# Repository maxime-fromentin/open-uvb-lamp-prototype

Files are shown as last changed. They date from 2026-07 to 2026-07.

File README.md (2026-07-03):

# Open UVB Lamp Prototype

Prototype narrowband UVB lamp using a Philips PL-S 9W/01/2P lamp, a G23 electromagnetic ballast, a FreeCAD-designed enclosure, and a mechanical relay controlled by a Seeed XIAO RP2040.

The project is documented in the context of localized narrowband UVB exposure research for psoriasis-related prototyping. It is not medical advice and does not claim to treat, cure, or diagnose psoriasis.

The photos and videos in this README are presentation assets for the physical prototype and its assembly. They are included for documentation and inspection only.

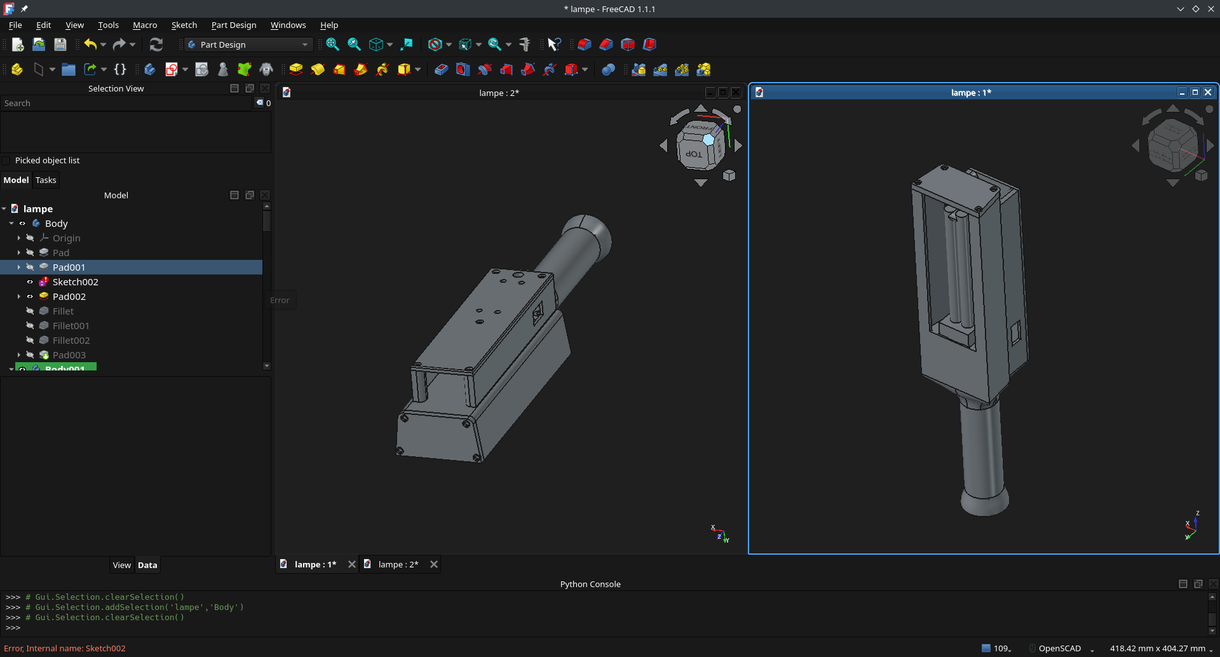
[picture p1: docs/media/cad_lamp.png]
CAD model


| Prototype handling | Visible lamp test |
| --- | --- |
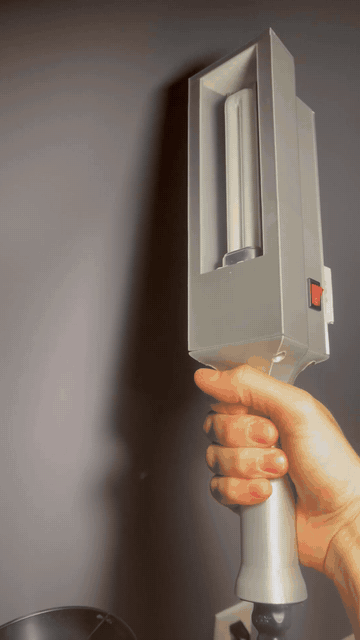
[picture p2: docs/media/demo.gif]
Prototype handling demo
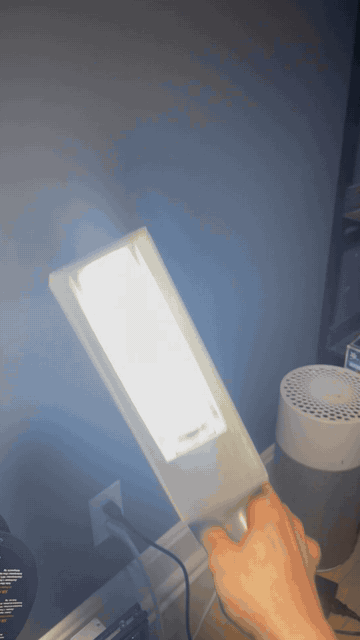
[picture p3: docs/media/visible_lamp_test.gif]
Visible non-UV lamp test
|  |  |

The illuminated lamp shown above is a visible, non-UV G23 test lamp used to verify fit, wiring behavior, and demonstration footage without UV exposure.

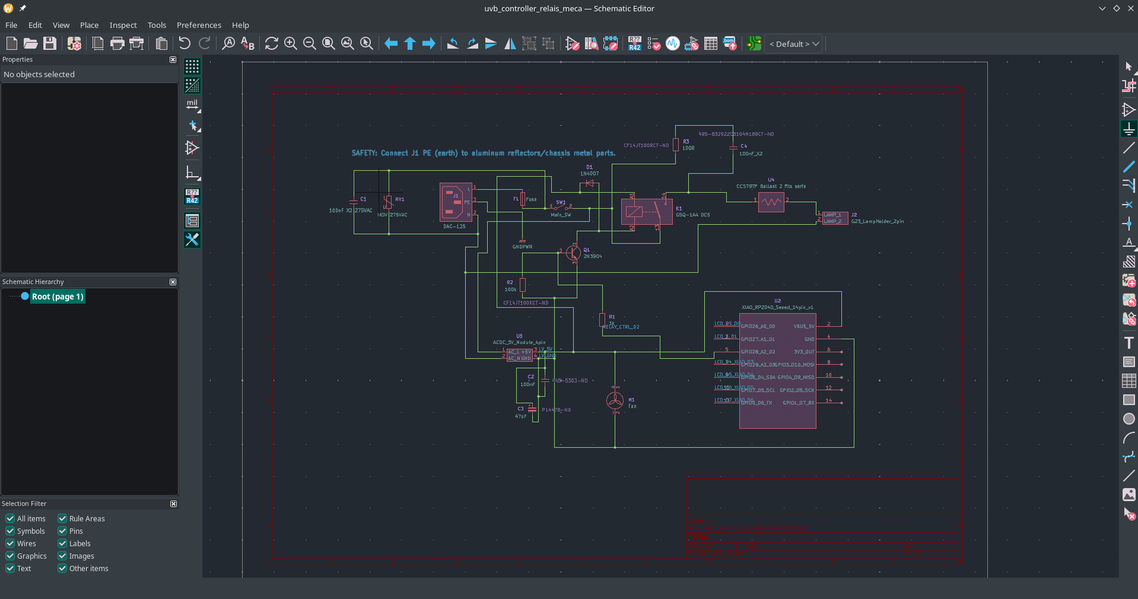
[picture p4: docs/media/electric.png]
Electrical schematic overview


Electrical schematic overview in KiCad. The schematic is provided as a wiring and soldering reference, not as a certified electrical validation.

> Project status: documented prototype. This repository is not a safety certification, a validated medical device, or a build guide for unqualified users.

## Critical Warning

This project combines 120 VAC mains voltage with a UVB source. UVB exposure can cause skin burns, eye injury, and long-term tissue damage. Mains voltage can kill.

The KiCad schematic is mainly a wiring and soldering aid for understanding the prototype. It is not a complete electrical simulation, a regulatory validation, a medical validation, or proof that the device is safe.

KiCad ERC/DRC checks can catch some connection errors, but they do not validate safety with mains voltage, ballasts, UVB lamps, or therapeutic use.

This repository is intended for documentation and private technical reference. It is not a certification file, a warranty of safety, or a substitute for qualified electrical, mechanical, or medical review.

## Burn-Risk Control Features

The prototype is designed around the idea that UVB exposure must be time-limited, distance-aware, and measured. These controls are intended to reduce burn risk, but they do not make the device medically safe by themselves:

- **Relay-controlled shutoff:** the lamp power path is switched by a mechanical relay so the controller can interrupt exposure.
- **Default-off firmware behavior:** the test firmware drives the relay OFF at boot and only turns it ON after an explicit command.
- **Short timed pulse during tests:** the current relay test firmware limits `on` and `pulse` commands to 5 seconds.
- **Physical shielding:** the enclosure concept is intended to block stray UV and expose only the target area.
- **Distance control concept:** a fixed distance guide or visual distance reference should be used because UV dose changes strongly with distance.
- **Cooling and thermal checks:** ventilation and temperature checks are part of the prototype notes because lamp temperature can affect output and enclosure safety.
- **Required UV measurement:** actual UVB irradiance must be measured with a suitable meter before any exposure assumptions are made.

These features are engineering risk controls, not a treatment protocol. Dose limits, exposure schedules, and suitability for psoriasis phototherapy require qualified medical guidance.

The media in this README show the prototype as built, including the FreeCAD enclosure, the visible non-UV test lamp, and the electrical layout. They are not proof of safety or clinical suitability.

## Retained Design

The retained design is the mechanical-relay schematic:

- KiCad source: `kicad_uvb_project/uvb_controller/uvb_controller_mechanical_relay.kicad_sch`
- KiCad project: `kicad_uvb_project/uvb_controller/uvb_controller.kicad_pro`
- Local symbol library: `kicad_uvb_project/uvb_controller/uvb_custom.kicad_sym`
- Schematic PDF: `output/pdf/uvb_controller_mechanical_relay.pdf`

Older schematic variants are kept in `kicad_uvb_project/uvb_controller/archive/` for historical reference only.

## Repository Contents

- `CAD/`: FreeCAD source files, STEP model, and mechanical reference images.
- `kicad_uvb_project/`: KiCad schematic, relay BOM, placement notes, and connection maps.
- `sketch_relay_test/`: XIAO RP2040 relay test firmware.
- `XIAO_RELAY_TEST_SOFTWARE.md`: compile, flash, and serial test notes.
- `SAFETY.md`: essential safety notes.
- `digikey_bom_clean.csv`: public supplier-oriented BOM with personal sourcing links removed.
- `docs/media/`: README media assets, including the demo GIF.

## Reproducing the Prototype

The repository includes the core files needed to inspect and reproduce the documented prototype:

- Mechanical design in FreeCAD: `CAD/lampe.FCStd`, `CAD/CadLampe.FCStd`, `CAD/Fan_80x80x38_equivalent.step`, and `CAD/G23_lamp_dimensions.md`.
- Electrical wiring reference: `kicad_uvb_project/uvb_controller/uvb_controller_mechanical_relay.kicad_sch` and `output/pdf/uvb_controller_mechanical_relay.pdf`.
- KiCad custom symbols: `kicad_uvb_project/uvb_controller/uvb_custom.kicad_sym`.
- Parts list: `digikey_bom_clean.csv` and `kicad_uvb_project/BOM_mechanical_relay.csv`.
- Firmware: `sketch_relay_test/sketch_relay_test.ino`.
- Firmware test notes: `XIAO_RELAY_TEST_SOFTWARE.md`.
- Safety notes: `SAFETY.md`.

Vendor datasheets are referenced by URL in the BOM rather than copied into the repository.

## Firmware Test

The test firmware forces the relay OFF at boot and waits for a serial command:

- `on`: turns the relay on for 5 seconds.
- `pulse`: same as `on`.
- `off`: immediately turns the relay off.
- `status`: prints the current state.

Keep mains voltage disconnected during USB and firmware tests.

## Minimum Validation Before Use

Before any mains or UVB test, document at least:

- protective earth continuity to accessible metal parts;
- no continuity between mains `L/N` and logic `5V/GND`;
- fuse on the live conductor;
- UV-opaque enclosure and ventilation;
- thermal measurement;
- UVB irradiance measurement with a suitable meter;
- ideally, a 250-400 nm spectral measurement.

## License

See `LICENSE.md`.

Proposed license split:

- Hardware, CAD, KiCad files, BOMs: CERN-OHL-P-2.0.
- Firmware: MIT.
- Documentation, photos, and videos: CC-BY-4.0.

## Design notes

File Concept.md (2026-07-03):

# Project Concept

The goal is to document a DIY narrowband UVB lamp prototype based on a Philips PL-S 9W/01/2P lamp. The design aims to capture practical FreeCAD files, wiring, BOM, safety, and test notes so that another technically competent person can understand the build.

This is not a finished medical device. The main value of the repository is transparency: mechanical files, wiring intent, BOM choices, test firmware, and safety assumptions are kept together.

The project is documented in a psoriasis-related prototyping context because narrowband UVB is commonly associated with clinical phototherapy. This repository does not provide a treatment protocol and does not claim medical efficacy.

## Target Lamp

- Philips UV-B Narrowband PL-S 9W/01/2P.
- G23 two-pin base.
- The lamp emits around 360 degrees, so a reflector is needed to avoid wasting much of the output.
- Internal wiring should use appropriately rated wire, such as AWG 18 or equivalent where suitable.

## Mechanical Ideas

- UV-opaque enclosure.
- Polished aluminum reflector.
- Light-trap ventilation path to block direct UV leakage while allowing airflow.
- Heat-resistant mounting near the lamp holder; PLA may soften near warm components.
- Metal or wood isolation plate around the lamp socket if needed.

## Controls and Safety Features

Potential features to document or add:

- redundant timer;
- visual distance guide, such as two angled lasers or a removable distance gauge;
- active cooling;
- red LCD display for readability through amber protective goggles;
- calibration or validation using a UVB meter;
- protective eyewear certified for UV exposure;
- skin shielding for areas that should not be exposed.

## Power and Ballast

The retained design uses a mechanical relay and an electromagnetic ballast approach. A conventional ferromagnetic ballast can be more tolerant in this kind of prototype than some compact electronic switching approaches, but every selected part still needs independent review.

Add a fuse holder on the live input conductor. A GFCI-protected outlet or power strip is strongly recommended for bench testing.

## Validation Ideas

- Use a spectroradiometer capable of measuring roughly 250-400 nm to verify the spectral output.
- Use a UVB radiometer, such as a Solarmeter-style meter, to measure irradiance in mW/cm2 at the actual working distance.
- Compare measurements against a known commercial phototherapy device only if the same measurement setup and distance are used.
- Use a thermal camera or contact temperature measurements to verify cooling.

## Risk Example

If the expected output is 3 mW/cm2 but the real build produces 6 mW/cm2 at the same distance, a two-minute exposure gives twice the intended dose. This is why measured output matters more than design assumptions.

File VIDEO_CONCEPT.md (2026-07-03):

# Video Concept

Goal: short demonstration video for the repository README and project page.

Suggested content:

- show the assembled prototype;
- show the mechanical layout and lamp holder;
- show the relay test behavior with mains disconnected where appropriate;
- include thermal and UV measurement footage when available;
- explain the limitations of the prototype without making medical claims.

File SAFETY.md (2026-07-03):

# Safety Notes

## Your Responsibilities

- **Competence:** do not reproduce or modify this build unless you have real electrical and mechanical competence for mains-powered UV equipment.
- **Shielding:** the enclosure must be fully opaque to UV radiation.
- **Eye protection:** use certified UV protective eyewear, for example EN 170 goggles marked `2C-1.2` or equivalent. Never look at the bare lamp, even briefly.
- **Ventilation:** UV lamps heat up, and their output spectrum can vary with temperature. Provide airflow if the lamp is enclosed.
- **Mains safety:** protect the live conductor with a fuse, bond accessible metal parts to protective earth, and keep mains wiring physically separated from low-voltage electronics.
- **Measurement:** do not rely on assumed dose. Measure UVB irradiance and, ideally, the emitted spectrum before any exposure.

This repository documents a prototype. It does not make the device medically or electrically safe by itself, and it does not replace professional review or local compliance obligations.

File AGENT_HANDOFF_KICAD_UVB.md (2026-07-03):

# Project Notes: UVB Prototype

This file is kept as a short public handoff note. It intentionally contains no personal paths, names, locations, credentials or private configuration.

## Current retained design

- Active electrical schematic: `kicad_uvb_project/uvb_controller/uvb_controller_mechanical_relay.kicad_sch`
- KiCad project: `kicad_uvb_project/uvb_controller/uvb_controller.kicad_pro`
- Local symbol library: `kicad_uvb_project/uvb_controller/uvb_custom.kicad_sym`
- Public schematic PDF: `output/pdf/uvb_controller_mechanical_relay.pdf`

## Design intent

The retained variant uses a mechanical relay controlled by a Seeed XIAO RP2040 relay driver circuit. The schematic is intended as a wiring and soldering aid for the prototype, not as a certified electrical design or complete simulation.

## Publication notes

- Do not publish API credentials, private supplier quotes, local filesystem paths or personal marketplace links.
- Keep obsolete schematic variants in `kicad_uvb_project/uvb_controller/archive/` only as historical references.
- Review the safety warning in `README.md` before publishing.

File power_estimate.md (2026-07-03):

# Power and Current Estimate

## Estimated Power

- Lamp + ballast: roughly 12 to 18 W, including ballast losses.
- Fan: roughly 1 to 15 W depending on the selected fan type.
- Control electronics: roughly 1 to 4 W.
- Typical total: roughly 14 to 37 W.

## Mains Current at 120 VAC

Using `I = P / V`:

- Low estimate: `14 W / 120 V = 0.117 A`
- High estimate: `37 W / 120 V = 0.308 A`

Use these values only as first-order sizing estimates. Actual current, inrush, ballast behavior, and thermal behavior must be measured on the assembled prototype.

## Relay and Control Note

The low-voltage XIAO output only controls the relay driver transistor. It does not power the AC load directly.

The relay contact, wiring, fuse, switch, inlet, ballast, and all mains clearances must be selected and reviewed for the real AC load, including inrush current.

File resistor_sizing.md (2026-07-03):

# SSR Input Resistor Sizing

Date: 2026-05-07

This note is retained for the earlier SSR variant. The retained public schematic now uses the mechanical relay design, but the calculation remains useful historical context.

## Context

- Microcontroller: ESP32-WROOM, 3.3 V GPIO.
- SSR candidate: Panasonic AQH3213.
- Datasheet assumptions:
  - input LED forward voltage: approximately `Vf = 1.2 to 1.3 V`;
  - maximum trigger LED current: `Ift_max = 10 mA`.

Goal: choose a series resistor that can trigger the SSR from a 3.3 V GPIO.

## Formula

SSR LED current:

`I = (Vgpio - Vf) / R`

with `Vgpio = 3.3 V`.

## Candidate Values

### R = 220 ohms

- With `Vf = 1.2 V`: `I = (3.3 - 1.2) / 220 = 9.55 mA`
- With `Vf = 1.3 V`: `I = (3.3 - 1.3) / 220 = 9.09 mA`

Conclusion: borderline against `Ift_max = 10 mA`.

### R = 180 ohms

- With `Vf = 1.2 V`: `I = 11.67 mA`
- With `Vf = 1.3 V`: `I = 11.11 mA`

Conclusion: better trigger margin while still keeping GPIO current reasonable.

### R = 150 ohms

- With `Vf = 1.2 V`: `I = 14.00 mA`
- With `Vf = 1.3 V`: `I = 13.33 mA`

Conclusion: more margin, but higher GPIO load.

## Resistor Dissipation

`P = I^2 * R`

For `R = 180 ohms`, at roughly 11.1 to 11.7 mA:

- `P_min ~ 0.022 W`
- `P_max ~ 0.025 W`

A 1/4 W resistor is sufficient.

## Historical Recommendation

- Recommended SSR input resistor: **180 ohms**.
- Use one series resistor per SSR input.
- Keep firmware logic explicit, with the output OFF at boot.
- A transistor or MOSFET driver can be added later for stronger logic isolation and drive margin.

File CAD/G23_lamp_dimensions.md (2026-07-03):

# G23 Lamp Dimensions

This note collects approximate dimensions used to model the 9 W G23 lamp for the project.

## Known or Standard Reference Values

- Maximum overall length: about 6.5 in = 165.1 mm, often rounded to 165-167 mm.
- Power: 9 W.
- Base: G23, 2 pins.

## Approximate Values to Validate

- Tube diameter: about 11 to 12 mm, T4-style tube.
- Pin spacing: about 7.8 mm, G23 standard.
- Pin diameter: about 0.9 to 1.0 mm.
- Visible pin length: about 6 to 8 mm.
- Maximum width, tube outside to tube outside: about 28 to 32 mm.
- Plastic base: about 31 x 15.5 x 16 mm.
- Base shoulder or neck: about 27 x 13 x 6 mm.

## Measurements Needed for Final CAD

1. Exact overall length from pin tip to top of U-bend.
2. Exact maximum width from outside tube to outside tube.
3. Exact tube diameter.
4. Exact pin spacing and pin diameter.
5. Exact depth and height of the G23 base block.
6. U-bend height and radius.

## Note

The approximate values above are suitable for a first 3D mockup, but final geometry should be validated against the real lamp or an exact manufacturer datasheet.

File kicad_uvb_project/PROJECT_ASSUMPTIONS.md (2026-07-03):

# UVB Controller - Default Assumptions

- Input mains: `120 VAC / 60 Hz`
- AC wiring and low-voltage control wiring must be physically separated.
- Controller: `Seeed XIAO RP2040`.
- AC-DC supply: isolated AC-to-5V module or enclosed supply suitable for the enclosure.
- AC switching: mechanical relay on Live (L), driven through a transistor stage.
- External power connector:
- Cable: `NEMA 5-15P to IEC C13`.
- Appliance inlet or panel connector: `IEC C14` or equivalent rated inlet.
- UV lamp path:
- electromagnetic ballast;
- G23 socket;
- Philips PL-S 9W/01/2P lamp.

## Safety Notes

- Keep AC and low-voltage wiring separated.
- Add a fuse on AC Live before the downstream switch/load path.
- Bond accessible metal parts to protective earth where applicable.
- Place AC wiring away from MCU headers and USB access.
- Final validation should include creepage, clearance, strain relief, enclosure, grounding, thermal, and local-code review.

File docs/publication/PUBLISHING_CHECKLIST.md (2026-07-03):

# Publishing Checklist

Use this before making the GitHub repository public.

## Must do

- Rotate any Digi-Key/API credentials that were ever stored in local notes.
- Confirm `Bom.md` contains no API credentials.
- Confirm no personal paths remain, for example `/home/<name>`, `/run/media/<name>` or local mount paths.
- Confirm no personal marketplace links, private quote PDFs, addresses, phone numbers or emails are included.
- Confirm `datasheet/Quote_*.pdf` is not published unless manually reviewed.
- Publish only the retained schematic PDF: `output/pdf/uvb_controller_mechanical_relay.pdf`.
- Keep `uvb_controller_mechanical_relay.kicad_sch` as the active schematic.
- Keep archived schematics clearly marked as historical if they are published.

## Recommended repository files

- `README.md`
- `LICENSE.md`
- `.gitignore`
- `SAFETY.md`
- `Concept.md`
- `Bom.md`
- `digikey_bom_clean.csv`
- `kicad_uvb_project/BOM_mechanical_relay.csv`
- `kicad_uvb_project/PLACEMENT_GUIDE.md`
- `kicad_uvb_project/PROJECT_ASSUMPTIONS.md`
- `kicad_uvb_project/uvb_controller/uvb_controller.kicad_pro`
- `kicad_uvb_project/uvb_controller/uvb_controller_mechanical_relay.kicad_sch`
- `kicad_uvb_project/uvb_controller/uvb_custom.kicad_sym`
- `output/pdf/uvb_controller_mechanical_relay.pdf`
- `CAD/`
- `sketch_relay_test/sketch_relay_test.ino`
- `XIAO_RELAY_TEST_SOFTWARE.md`
- `docs/media/demo.gif` once available

## Do not publish by default

- `.tools/`
- `.arduino15/`
- `.code/`, `.agents/`, `.codex/`
- `build_relay_test/`
- `kicad_uvb_project/uvb_controller/fp-info-cache`
- `kicad_uvb_project/uvb_controller/uvb_controller-backups/`
- `datasheet/Quote_*.pdf`
- downloaded vendor datasheets unless their redistribution terms are clear

## Final safety wording

Make sure the README clearly states that the KiCad schematic is a wiring and soldering aid, not a certified electrical design, medical device validation, or complete numerical simulation.

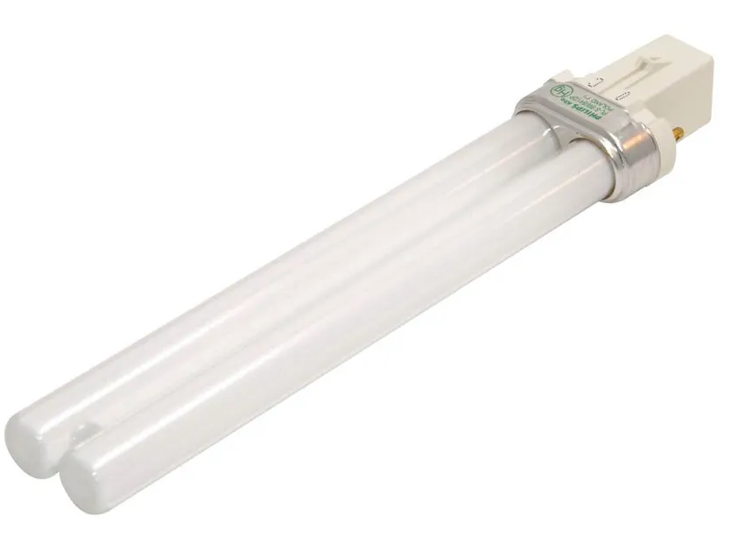
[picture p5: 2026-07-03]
CAD/Ampoule2.png

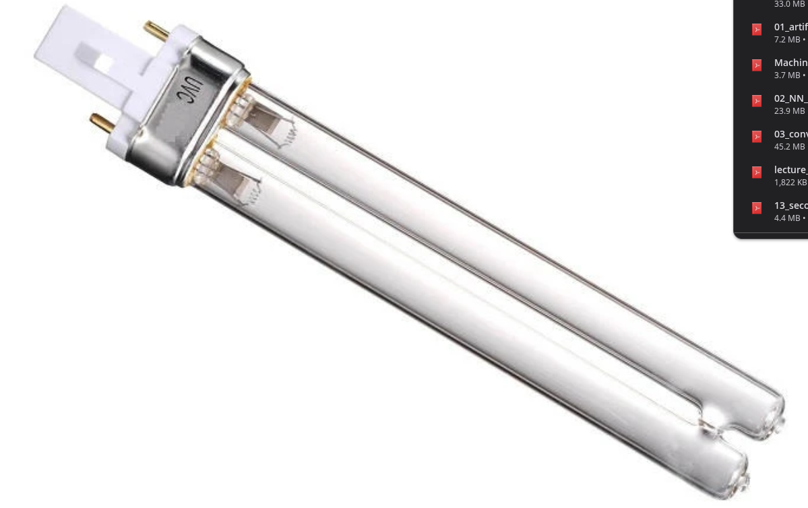
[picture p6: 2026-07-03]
CAD/Ampoule.png

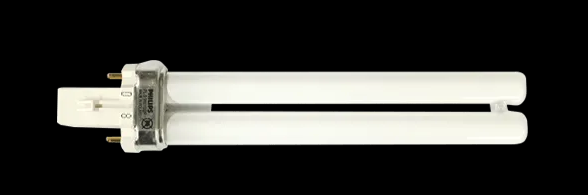
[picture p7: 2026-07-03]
CAD/Ampoule_cote.png

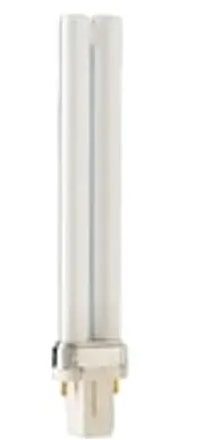
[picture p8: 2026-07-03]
CAD/Ampoule3.png

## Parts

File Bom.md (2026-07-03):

# BOM Notes

This file is an informal sourcing note. The structured public BOM is `digikey_bom_clean.csv`, and the KiCad-oriented relay BOM is `kicad_uvb_project/BOM_mechanical_relay.csv`.

## Main Items

- G23 lamp holder.
- Philips PL-S 9W/01/2P narrowband UVB lamp.
- Electromagnetic ballast compatible with the selected lamp.
- EN 170 or equivalent UV protective goggles.
- UV protective sleeve or shielding for non-target skin.
- AC fan or DC fan, depending on final enclosure design.
- AC-to-5V power module for the low-voltage control electronics.
- Seeed XIAO RP2040 relay controller.
- External mains cord and appliance inlet.
- Main AC switch.
- Fuse holder and fuse on live conductor.
- Polished aluminum reflector.
- Perfboard or prototyping board for the control circuit.
- Headers or sockets for removable controller mounting.

## Publication Note

Do not store API credentials, private supplier quotes, personal addresses, private marketplace links, or local filesystem paths in this repository. Use local environment variables for supplier API integrations.

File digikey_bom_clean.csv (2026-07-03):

item | number | manufacturer | mpn | unit_price_cad | quantity_available | airflow_cfm | product_description | detailed_description | product_url | datasheet_url | status
Appliance inlet IEC C14 panel mount | 1 | DIT | DAC-12S | 0.97 | 161 |  | IEC 60320 C14 appliance inlet panel mount | Input connector for external C13 power cord | https://www.digikey.com/en/products/detail/dit/DAC-12S/18681274 | //mm.digikey.com/Volume0/opasdata/d220001/medias/docus/5561/DAC%20Series.pdf | ready
Main AC rocker switch | 1 | ZF Electronics | SRB22A2FBRNN | 2.38 | 3201 |  | Rocker switch SPST 10A 125V | Main 120 VAC switch with current margin | https://www.digikey.com/en/products/detail/zf-electronics/SRB22A2FBRNN/446027 | https://switches-sensors.zf.com/wp-content/uploads/2024/08/Rocker_SRB_Datasheet_2024-08-02.pdf | ready
Panel fuse holder 5x20mm | 1 | Littelfuse Inc. | 82000000005 | 5.02 | 5163 |  | Fuse holder panel mount 5x20mm | Accessible enclosure fuse holder in series with Live | https://www.digikey.com/en/products/detail/littelfuse-inc/82000000005/653481 | https://www.littelfuse.com/assetdocs/820-821-823-824-series-datasheet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 | ready
Slow-blow fuse 5x20mm 250V | 2 | Bel Fuse Inc. | 5HT 1-R | 0.74 | 5193 |  | Fuse cartridge 5x20mm slow-blow 1A 250V | Main fuse plus one spare | https://www.digikey.com/en/products/detail/bel-fuse-inc/5HT-1-R/1008979 |  | ready
Slow-blow fuse 5x20mm 250V alternative | 2 | Bel Fuse Inc. | 5HT 1.6-R | 0.74 | 2573 |  | Fuse cartridge 5x20mm slow-blow 1.6A 250V | Alternative if startup inrush trips the 1A fuse | https://www.digikey.com/en/products/detail/bel-fuse-inc/5HT-1-6-R/1008981 |  | optional
AC SSR alternative | 0 | Panasonic Industry | AQH3213 | 2.69 | 2256 |  | SSR SPST-NO 1.2A 0-600V PhotoMOS | Historical alternative only; less robust for inductive ballast loads than mechanical relay | https://www.digikey.com/en/products/detail/panasonic-industry/AQH3213/2125782 | //mm.digikey.com/Volume0/opasdata/d220001/medias/docus/8457/AQ-H%20RELAYS.pdf | optional
Main AC mechanical relay | 2 | Omron Electronics Inc-EMC Div | G5Q-1A4 DC5 | 1.77 | 4715 |  | Relay SPST-NO 5V coil 10A 277VAC through-hole | Primary ballast/lamp switching relay; one installed plus one spare | https://www.digikey.com/en/products/detail/omron-electronics-inc-emc-div/G5Q-1A4-DC5/1815721 | https://components.omron.com/sites/default/files/datasheet_pdf/J155-E1.pdf | ready
NPN relay driver transistor | 4 | Diotec Semiconductor | 2N3904 | 0.14 | 75720 |  | NPN transistor through-hole TO-92 | Relay coil driver from XIAO GPIO | https://www.digikey.com/en/products/detail/diotec-semiconductor/2N3904/13164701 | https://diotec.com/request/datasheet/2n3904.pdf | ready
Relay flyback diode | 4 | Diotec Semiconductor | 1N4007 | 0.14 | 334537 |  | Rectifier diode 1kV 1A through-hole | Flyback protection across relay coil | https://www.digikey.com/en/products/detail/diotec-semiconductor/1N4007/18833652 | https://diotec.com/request/datasheet/1n4001.pdf | ready
Relay driver base resistor | 4 | Stackpole Electronics Inc | RNMF14FTC1K00 | 0.14 | 4024 |  | Through-hole resistor 1k ohm 1/4W 1% | Limits transistor base current | https://www.digikey.com/en/products/detail/stackpole-electronics-inc/RNMF14FTC1K00/2617329 | https://www.seielect.com/catalog/SEI-RNF_RNMF.pdf | ready
Electromagnetic ballast 120VAC 1x9W G23 | 1 | Candela Corporation | CC579TP | 18.28 | 54 |  | Magnetic ballast candidate for Philips PL-S 9W/01/2P | G23 2-pin 7W/9W compatible; supplier listing price converted from USD at 1.4 | https://www.candelacorp.com/product/CC579TP |  | ready
G23 2-pin lamp holder | 2 | Candela Corporation | 1185-9-2H | 2.52 | 37 |  | Lampholder/socket for PL-S 9W/01/2P | Selected option for chassis mounting; supplier listing price converted from USD at 1.4 |  | https://www.candelacorp.com/spec/?prod_num=1185-9-2H | ready
G23 2-pin lamp holder alternative | 0 | Candela Corporation | 1185-9-VS1 | 2.52 | 25 |  | Vertical snap-in G23 socket | Alternative only | https://www.candelacorp.com/spec/?prod_num=1185-9-VS1 |  | optional
UVB lamp PL-S 9W/01/2P | 1 | Philips | PL-S 9W/01/2P | 75.00 | available |  | Narrowband UVB lamp | Target compatibility lamp; verify availability before ordering | https://solarcsystems.ca/product/philips-pl-s9w01-bulb/ |  | not_selected
XIAO RP2040 controller | 2 | Seeed Technology Co. Ltd | 102010428 | 7.05 | 4275 |  | Seeed XIAO RP2040 | Low-voltage relay controller board | https://www.digikey.com/en/products/detail/seeed-technology-co-ltd/102010428/14672129 | https://files.seeedstudio.com/wiki/XIAO-RP2040/res/rp2040_datasheet.pdf | ready
External wall-to-device power cord | 1 | Same Sky | AC-C13-NA | 6.7 | 21787 |  | NEMA 5-15P to IEC 60320 C13 power cord | 18 AWG 3-conductor 6 ft cord | https://www.digikey.com/en/products/detail/same-sky-formerly-cui-devices/AC-C13-NA/3479176 | https://www.sameskydevices.com/product/resource/digikeypdf/ac-c13-na.pdf | ready
USB-A to USB-C programming cable | 1 | GlobTek Inc. | USBA2C1MOUSBC(R) | 2.71 | 5334 |  | USB 2.0 cable Type-A male to Type-C male | Programming and test cable for XIAO RP2040 | https://www.digikey.com/en/products/detail/globtek-inc/USBA2C1MOUSBC-R/12546298 |  | ready
Internal AWG18 wire | 1 | Generic | 18 AWG stranded hookup wire | 19.95 | available |  | Hook-up wire for internal wiring | Use wire with appropriate voltage and temperature rating |  |  | ready
5V DC fan | 1 | Qualtek | FAD1-04010BBLW11 | 8.88 | 1668 | 4.2 | Fan axial 40x40x10mm ball 5VDC | Low-voltage cooling fan candidate | https://www.digikey.com/en/products/detail/qualtek/FAD1-04010BBLW11/2600052 |  | ready
Male 2.54mm headers for XIAO | 2 | Same Sky | SSK01-MPH-254-A7 | 0.23 | 4988 |  | Header strip 1x7 2.54mm through-hole | Allows XIAO pins to plug into socket headers | https://www.digikey.com/en/products/detail/same-sky-formerly-cui-devices/SSK01-MPH-254-A7/28772111 | https://www.sameskydevices.com/product/resource/digikeypdf/ssk01-mph-254.pdf | ready
Female 2.54mm socket headers for XIAO | 2 | Adam Tech | RS1-07-G | 0.62 | 2772 |  | Socket header 1x7 2.54mm through-hole | Removable XIAO mounting on protoboard | https://www.digikey.com/en/products/detail/adam-tech/RS1-07-G/9832045 | https://app.adam-tech.com/products/download/data_sheet/203013/rs1-xx-g-data-sheet.pdf | ready
UV protective arm sleeve | 1 | Generic | UV protective arm sleeve | 5.00 | available |  | UV protective sleeve for non-target skin | Verify UV rating before use |  |  | ready
UV protective goggles EN 170 | 1 | Solarc Systems / SolRx | UV Protective Patient Goggle - Amber Tint | 24.84 | available |  | Patient UV protective goggles | Supplier listing states UV and blue-light blocking | https://solarcsystems.com/product/uv-protective-patient-goggles-amber-tint/ |  | ready
Polished aluminum reflector sheet | 1 | Generic | Polished aluminum sheet | 2.00 | available |  | Polished or polishable aluminum reflector material | Avoid publishing personal marketplace links |  |  | ready
Compact protoboard 80x50mm | 2 | BusBoard Prototype Systems | PAD1 | 6.00 | 184 |  | FR4 perfboard 80mm x 50mm 2.54mm | Compact prototyping board for relay and control wiring | https://www.digikey.com/en/products/detail/busboard-prototype-systems/PAD1/19200381 | http://www.busboard.com/documents/datasheets/BPS-DAT-(PAD1)-Datasheet.pdf | ready
Visible G23 9W test lamp | 1 | Candela Corporation | PL-S9W/41 | 10.63 | 38 |  | 9W 4100K G23 visible lamp | Visible-light test lamp option | https://www.candelacorp.com/product/PL-S9W/41 |  | ready
Visible G23 9W test lamp alternative | 0 | Candela Corporation | F9TT/27K | 10.63 | 31 |  | 9W 2700K G23 visible lamp | Visible-light test lamp alternative | https://www.candelacorp.com/product/F9TT/27K |  | optional
Supplier shipping estimate | 1 | Candela/UPS | SHIPPING_Candela_UPS | 35.00 |  |  |  | Verify shipping at checkout |  |  | ready
Enclosed AC/DC 5V 15W module | 2 | MEAN WELL USA Inc. | RS-15-5 | 8.60 | 617 |  | Enclosed AC/DC converter 85-264VAC to 5VDC 15W | Chassis-mounted enclosed power supply option | https://www.digikey.com/en/products/detail/mean-well-usa-inc/RS-15-5/7706168 | https://www.meanwell.com/Upload/PDF/RS-15/RS-15-SPEC.PDF | ready
MOV 275VAC across L-N | 2 | TDK Electronics | B72214S0271K101 | 0.25 | 17844 |  | Varistor MOV 275VAC radial | Mains transient suppression across Live-Neutral after fuse | https://www.digikey.com/en/products/detail/tdk/B72214S0271K101/593838 |  | ready
MOV 275VAC robust alternative | 0 | TDK Electronics | B72214S2271K151 | 0.37 | 12881 |  | Varistor MOV 275VAC radial 6kA | Higher surge-energy alternative | https://www.digikey.com/en/products/detail/tdk/B72214S2271K151/6159482 |  | optional
X2 safety capacitor 0.1uF 305VAC | 2 | TDK Electronics | B32922C3104M189 | 0.47 | 78499 |  | Film capacitor safety class X2 through-hole | EMI/RFI filtering across Live-Neutral after fuse | https://www.digikey.com/en/products/detail/tdk/B32922C3104M189/2269407 |  | ready

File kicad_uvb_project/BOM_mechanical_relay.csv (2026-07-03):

reference | category | value | notes
C1 | Capacitor | 100nF X2 275VAC | Mains safety capacitor across L-N after F1
D1 | Diode | 1N4007 | Flyback diode across relay coil
F1 | Fuse | Fuse | Mains input fuse on live
J1 | Connector | DAC-12S | IEC C14 AC input
J2 | Connector | G23_LampHolder_2pin | G23 lamp holder / socket
K1 | Relay | G5Q-1A4 DC5 | Mechanical relay coil 5VDC SPST-NO
M1 | Fan | Fan | 5V fan on low-voltage rail
Q1 | Transistor | 2N3904 | NPN relay driver transistor
R1 | Resistor | 1k | Base resistor for Q1 from XIAO GPIO28_A2_D2
RV1 | Varistor | MOV 275VAC | Mains surge suppressor across L-N after F1
SW1 | Switch | Main_SW | Main AC switch
U2 | MCU | XIAO_RP2040_Seeed_14pin_v1 | Main controller board/header
U4 | Ballast | Ballast_1xLamp_4pin | Ballast interface / terminal abstraction
U5 | ACDC | ACDC_5V_Module_4pin | AC-DC 5V module

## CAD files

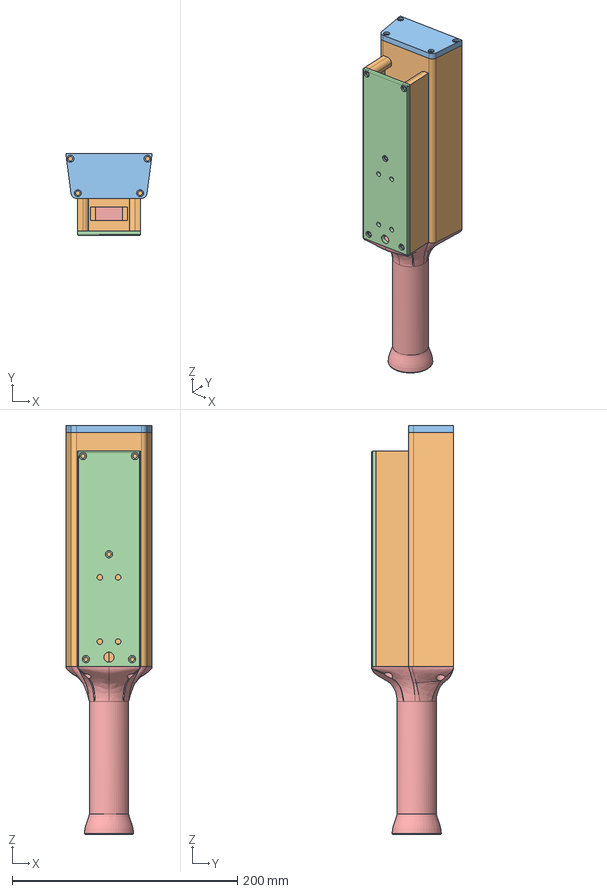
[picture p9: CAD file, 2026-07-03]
CAD/lampe.FCStd
76.7 x 73.0 x 363.0 mm

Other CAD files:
CAD/CadLampe.FCStd
CAD/Fan_80x80x38_equivalent.step

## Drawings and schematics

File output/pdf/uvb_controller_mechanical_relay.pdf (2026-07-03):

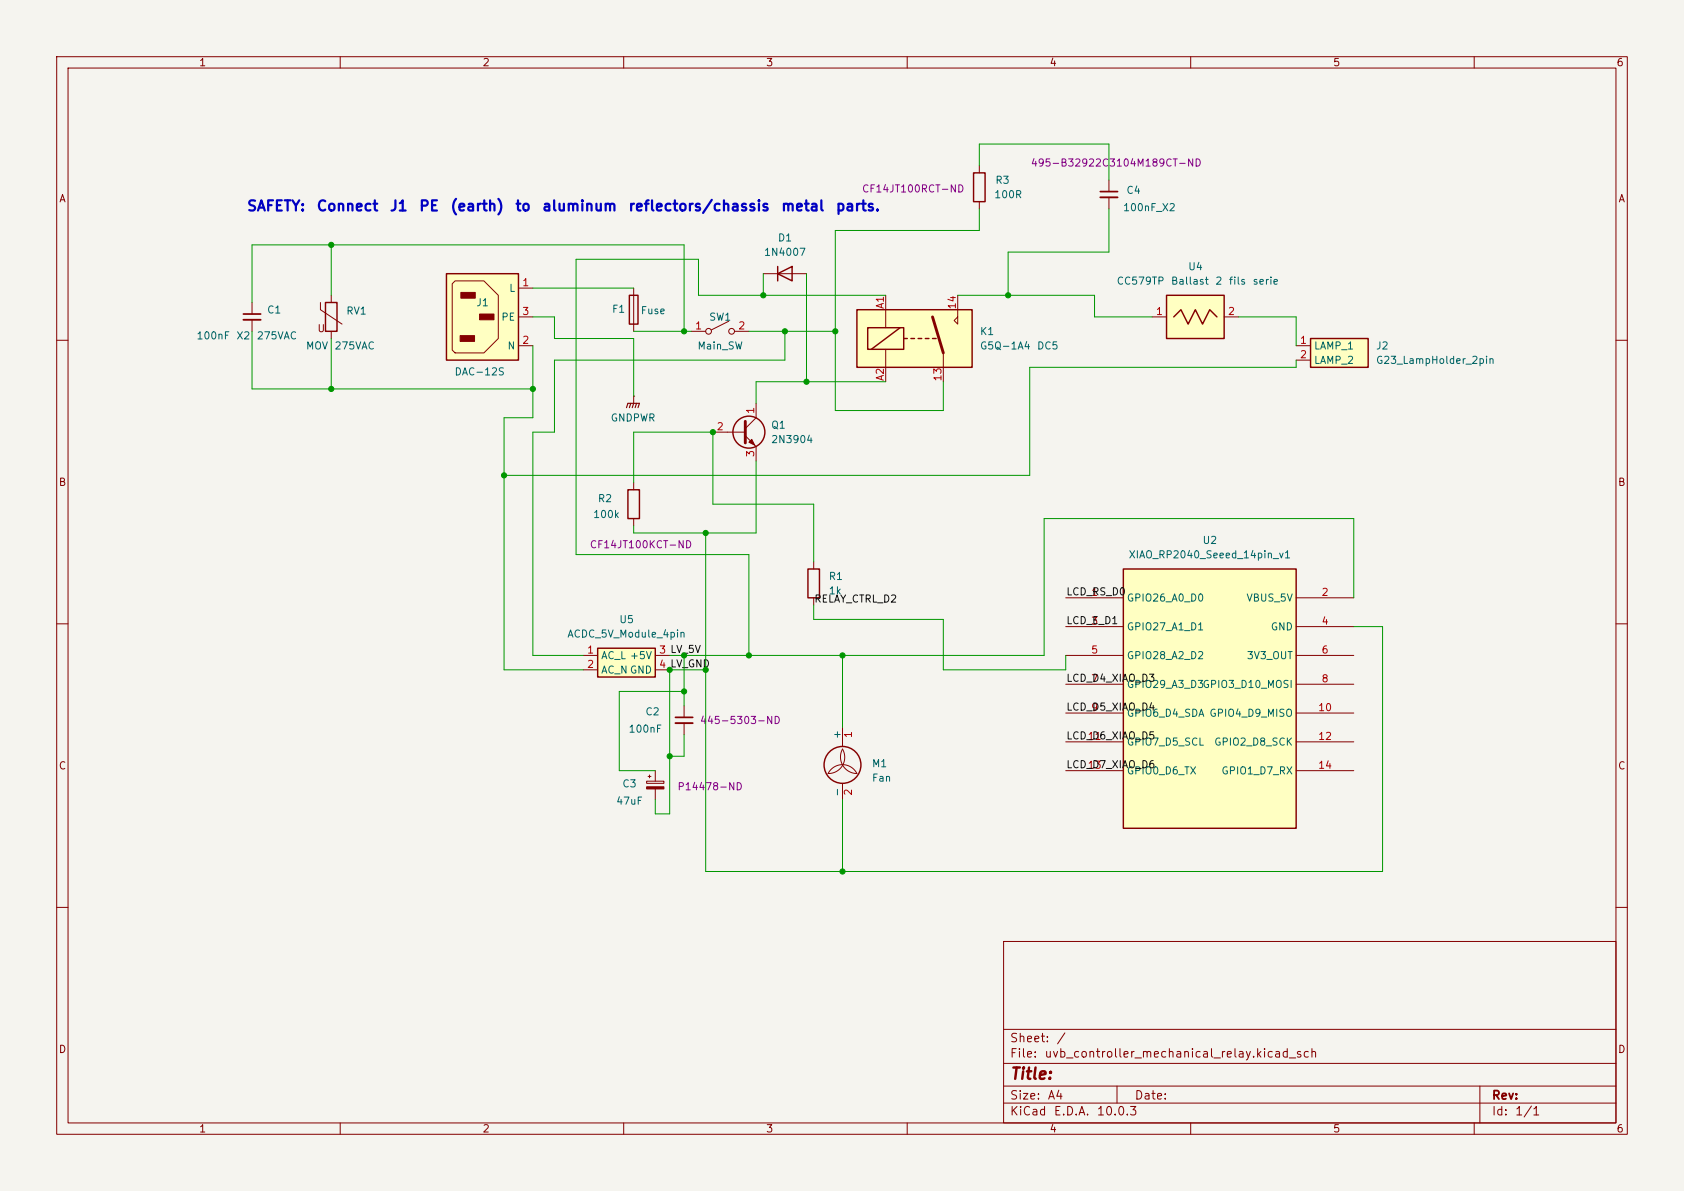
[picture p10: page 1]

SAFETY: Connect J1 PE (earth) to aluminum reflectors/chassis metal parts.

Size: A4 | Rev:
KiCad E.D.A. 10.0.3 | Id: 1/1

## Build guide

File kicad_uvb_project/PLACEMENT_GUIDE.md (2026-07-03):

# Placement Guide

## Board zoning
- Keep the AC power path (`J1`, `F1`, `SW1`, `K1`, `J2`) clearly separated from low-voltage logic (`U2`, `Q1`, `R1`, control headers).
- Keep a no-man's boundary corridor (at least 6 to 8 mm) between AC and LV zones.

## Suggested origin and mechanical coordinates
- Board origin: bottom-left corner
- `J1` (IEC C14 or AC terminal): near left edge center
- `F1`: between `J1` and `SW1`
- `SW1`: near top-left edge for front-panel access
- `K1`: center-left, with safe separation from logic wiring
- `J2` (to ballast): left-bottom edge or left-mid edge
- `U1` (AC-DC module): right of AC zone boundary, top-right quadrant
- `U2` (XIAO header area): mid-right quadrant
- `Q1` and `R1`: near the relay coil control path on the low-voltage side

## Routing priorities
- Route AC first (short, wide traces).
- Route relay contact wiring on Live with clear spacing.
- Route LV command lines away from AC paths.
- Create dedicated netclass for AC (`wider traces`, `higher clearance`).

## Track and clearance starting points
- LV logic traces: 0.25 to 0.30 mm
- LV power traces (5V/GND): 0.50 mm
- AC traces: 1.2 mm minimum recommended start
- Clearance LV-to-AC: target 3.0 mm minimum, prefer more when possible

## Final checks
- ERC review in schematic editor
- DRC review in PCB editor if a PCB is produced
- 3D viewer: connector accessibility and vertical component collisions
- Verify switch orientation and connector mating direction

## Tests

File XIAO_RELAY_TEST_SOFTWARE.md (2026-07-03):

# XIAO RP2040 Relay Test Software

This document summarizes the test firmware used to program and validate the Seeed XIAO RP2040 relay-control path.

## Hardware Context

- Detected board: `Seeed XIAO RP2040`
- Typical Linux serial port: `/dev/ttyACM0`
- Relay-control pin: `D2 / GPIO28`
- Target logic wiring:

```text
XIAO D2 / GPIO28 -> R1 1k -> 2N3904 base
XIAO GND -> 2N3904 emitter
2N3904 collector -> relay coil A2
XIAO VBUS_5V -> relay coil A1
D1 flyback diode across the relay coil, diode stripe toward +5V/A1
```

Keep mains voltage disconnected during all USB and firmware tests.

## Tooling

The test was built with `arduino-cli` and the Earle Philhower RP2040 Arduino core:

```text
https://github.com/earlephilhower/arduino-pico/releases/download/global/package_rp2040_index.json
```

Target board:

```text
Seeed XIAO RP2040
FQBN: rp2040:rp2040:seeed_xiao_rp2040
```

Example setup:

```bash
arduino-cli config init --overwrite --additional-urls https://github.com/earlephilhower/arduino-pico/releases/download/global/package_rp2040_index.json
arduino-cli core update-index
arduino-cli core install rp2040:rp2040
```

## Firmware Behavior

Firmware path:

```text
sketch_relay_test/sketch_relay_test.ino
```

Serial commands:

```text
on     -> relay ON for 5 seconds, then automatic OFF
pulse  -> same as on
off    -> immediate relay OFF
status -> print current relay state
```

The relay is forced OFF at boot:

```cpp
pinMode(RELAY_PIN, OUTPUT);
digitalWrite(RELAY_PIN, LOW);
```

Important constants:

```cpp
constexpr uint8_t RELAY_PIN = D2;
constexpr unsigned long RUN_MS = 5000;
constexpr bool AUTO_START_ON_BOOT = false;
```

## Compile

```bash
arduino-cli compile --fqbn rp2040:rp2040:seeed_xiao_rp2040 sketch_relay_test
```

Observed result:

```text
Sketch uses 54660 bytes (2%) of program storage space.
Global variables use 8944 bytes (3%) of dynamic memory.
```

## Upload

Automatic upload example:

```bash
arduino-cli upload -p /dev/ttyACM0 --fqbn rp2040:rp2040:seeed_xiao_rp2040 sketch_relay_test
```

Manual UF2 flow:

```bash
arduino-cli compile --fqbn rp2040:rp2040:seeed_xiao_rp2040 --output-dir build_relay_test sketch_relay_test
cp build_relay_test/sketch_relay_test.ino.uf2 /run/media/<user>/RPI-RP2/
sync
```

To enter bootloader mode on the XIAO RP2040, hold BOOT, press RESET, then release BOOT.

## Serial Tests

Configure the serial port:

```bash
stty -F /dev/ttyACM0 115200 raw -echo
```

Check status:

```bash
printf 'status\n' > /dev/ttyACM0
```

Expected response:

```text
STATUS_OFF
```

Start a 5-second relay pulse:

```bash
printf 'on\n' > /dev/ttyACM0
```

Expected response:

```text
RELAY_ON
TIMER_5S_STARTED
RELAY_OFF
TIMER_DONE
```

## Bench Validation

The final relay test should be performed with mains disconnected and USB only.

Recommended multimeter check:

```text
Continuity mode between relay contact 13 and 14.
Idle: no continuity.
Command on: continuity for about 5 seconds.
After timeout: no continuity.
```

## Safety Notes

- Never connect mains during USB tests unless the whole prototype has been isolated and independently reviewed.
- Never connect USB to a computer if there is any possible accidental connection between mains and low-voltage circuitry.
- Before USB testing, verify there is no continuity between mains `L/N` and logic `5V/GND`.
- This test firmware is not a final redundant safety timer for a UVB device.

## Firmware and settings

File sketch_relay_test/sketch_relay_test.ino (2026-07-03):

// XIAO RP2040 relay smoke test.
// Hardware: D2/GPIO28 -> 1k -> 2N3904 base -> relay coil driver.

constexpr uint8_t RELAY_PIN = D2;
constexpr unsigned long RUN_MS = 5000;
constexpr unsigned long AUTO_START_DELAY_MS = 3000;
constexpr bool AUTO_START_ON_BOOT = false;

bool relayOn = false;
unsigned long relayUntil = 0;
String line;

void setRelay(bool on) {
  relayOn = on;
  digitalWrite(RELAY_PIN, on ? HIGH : LOW);
  if (!on) {
    relayUntil = 0;
  }
  Serial.println(on ? "RELAY_ON" : "RELAY_OFF");
}

void handleCommand(String cmd) {
  cmd.trim();
  cmd.toLowerCase();

  if (cmd == "on") {
    setRelay(true);
    relayUntil = millis() + RUN_MS;
    Serial.println("TIMER_5S_STARTED");
  } else if (cmd == "off") {
    setRelay(false);
  } else if (cmd == "pulse") {
    setRelay(true);
    relayUntil = millis() + RUN_MS;
    Serial.println("TIMER_5S_STARTED");
  } else if (cmd == "status") {
    Serial.println(relayOn ? "STATUS_ON" : "STATUS_OFF");
  } else if (cmd.length() > 0) {
    Serial.println("Commands: on, off, pulse, status");
  }
}

void setup() {
  pinMode(RELAY_PIN, OUTPUT);
  digitalWrite(RELAY_PIN, LOW);

  Serial.begin(115200);
  delay(1500);
  Serial.println("XIAO_RP2040_RELAY_TEST_READY");
  Serial.println("Commands: on, off, pulse, status");

  if (AUTO_START_ON_BOOT) {
    Serial.println("AUTO_START_WAIT_3S");
    delay(AUTO_START_DELAY_MS);
    setRelay(true);
    relayUntil = millis() + RUN_MS;
    Serial.println("AUTO_START_TIMER_5S_STARTED");
  }
}

void loop() {
  while (Serial.available() > 0) {
    char c = static_cast<char>(Serial.read());
    if (c == '\n' || c == '\r') {
      handleCommand(line);
      line = "";
    } else {
      line += c;
    }
  }

  if (relayUntil != 0 && static_cast<long>(millis() - relayUntil) >= 0) {
    setRelay(false);
    Serial.println("TIMER_DONE");
  }
}

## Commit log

2026-07-03 Initial public release
    [BOM_mechanical_relay.csv, CadLampe.FCStd, FOOTPRINT_MAP.csv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]
2026-07-03 Add CAD preview to README
2026-07-03 Add electrical schematic preview
